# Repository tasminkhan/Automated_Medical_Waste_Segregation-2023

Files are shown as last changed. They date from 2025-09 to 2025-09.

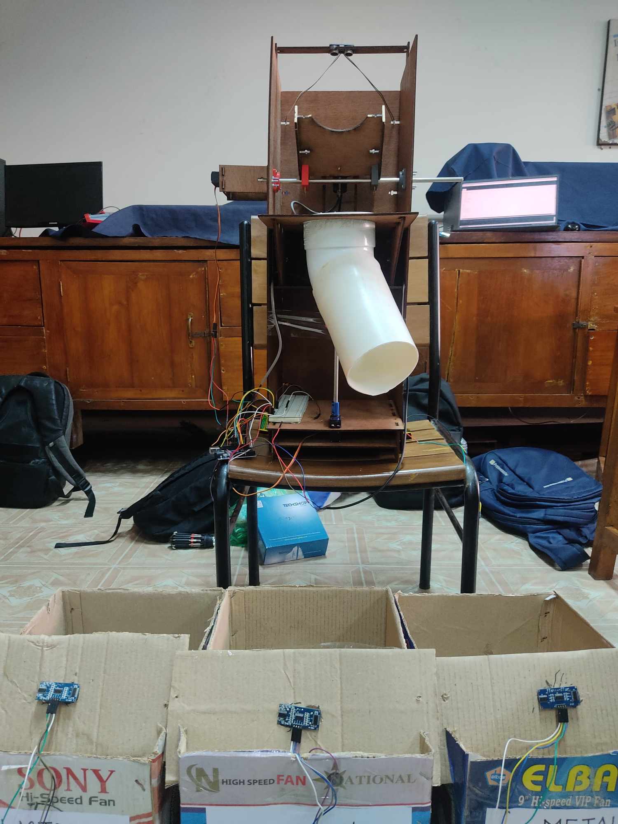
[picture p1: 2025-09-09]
media/laboratory setup.jpg

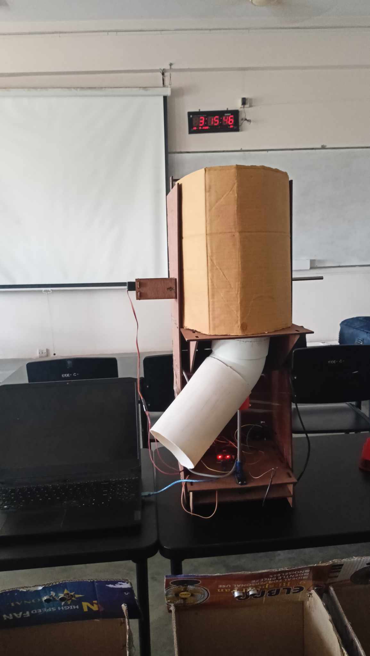
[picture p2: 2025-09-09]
media/model photo.jpg

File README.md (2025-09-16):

# Automated Smart Medical Waste Segregation System



An automated waste segregation system designed for medical facilities to efficiently sort waste into metallic, plastic, and organic categories using sensor technology and servo-controlled sorting mechanisms.

## Project Overview

This system addresses the critical need for proper medical waste management by automatically detecting and sorting different types of waste materials. The project focuses on healthcare applications where proper waste segregation is essential for safety and environmental compliance.

### Key Features

- **Multi-sensor Detection**: Uses capacitive, inductive, and ultrasonic sensors for waste identification
- **Automated V-Gate Sorting**: Servo motor-controlled mechanism for precise waste segregation
- **Smart Notifications**: Bluetooth-enabled system for waste bin level monitoring
- **Medical Focus**: Designed specifically for hospital and healthcare facility requirements
- **Sustainable Design**: Built with eco-friendly and cost-effective materials

## 🛠️ System Components

### Hardware
- **Microcontroller**: Arduino Uno
- **Sensors**: 
  - Capacitive proximity sensor (wet/organic waste detection)
  - Inductive proximity sensor (metal detection)  
  - 4x Ultrasonic sensors HC-SR04 (waste detection & bin level monitoring)
- **Actuators**: 2x TowerPro MG996R servo motors
- **Communication**: Bluetooth HC-05 module
- **Power**: 9V DC supply with step-down converter
- **Structure**: Laser-cut 4mm plywood frame, 3D printed components

### Software
- Arduino IDE for microcontroller programming
- SolidWorks for mechanical design
- Mobile app for notifications

## Performance Results

- **Detection Accuracy**: 90% (18/20 test samples)
- **Segregation Accuracy**: 80% (16/20 successful sorts)
- **Waste Categories**: Metal, Plastic, Organic/Biodegradable
- **Processing**: Real-time waste classification and sorting

## System Architecture

```
Waste Input → Ultrasonic Detection → Material Classification → V-Gate Sorting → Designated Bins
     ↓
Bin Level Monitoring → Bluetooth Alert → Mobile Notification
```

## How It Works

1. **Detection**: Ultrasonic sensor detects when waste is placed in the system
2. **Classification**: 
   - Metal waste: Both capacitive and inductive sensors detect
   - Organic/wet waste: Only capacitive sensor detects
   - Plastic waste: Neither sensor detects (default category)
3. **Sorting**: Servo motors control V-gate mechanism to direct waste to appropriate bin
4. **Monitoring**: Ultrasonic sensors in bins monitor fill levels
5. **Notification**: Bluetooth module sends alerts when bins reach 80% capacity

## Cost Analysis
**Total Project Cost**: 15,000 BDT (~$140 USD)

## Future Enhancements

- Integration of computer vision for improved detection
- Expansion to additional waste categories
- Central waste management dashboard

## References

This project builds upon established waste sorting principles and incorporates improvements for medical waste applications. 
- Instructables - [Automatic Waste Sorting Machine](https://www.instructables.com/Automatic-Waste-Sorting-Machine/)
- Ahmad, I., Mukhlisin, M., & Basri, H. (2016). Application of Capacitance Proximity Sensor for the Identification of Paper and Plastic from Recycling Materials.
- Wulandari, E. W. V. (2020). Waste segregator system design. IOP Conference Series: Materials Science and Engineering.
- Singh, N., Ogunseitan, O. A., & Tang, Y. (2022). Medical waste: Current challenges and future opportunities for sustainable management.

## 📄 License

This project is licensed under the MIT License - see the LICENSE file for details.

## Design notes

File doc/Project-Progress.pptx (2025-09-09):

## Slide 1

EEE 318: Control Systems I Laboratory

AUTOMATED
SMART WASTE
SEGREGATION

Project Progress

Group 06 | Presentation

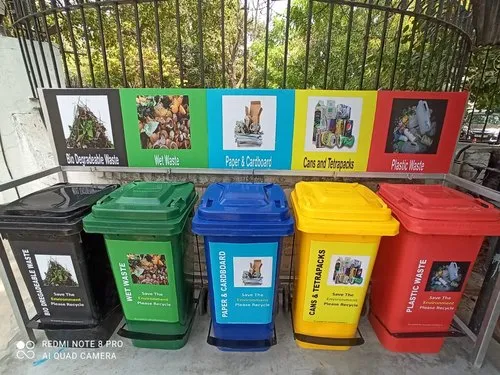
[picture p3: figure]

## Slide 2

EXPECTED STRUCTURE

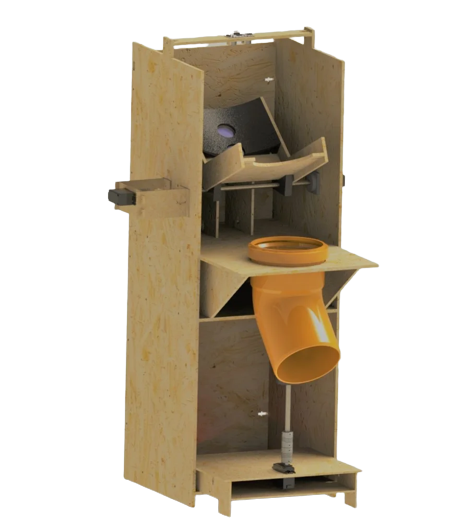
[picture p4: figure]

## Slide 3

PHYSICAL STRUCTURE

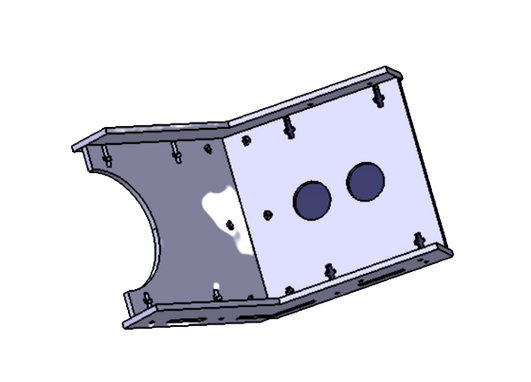
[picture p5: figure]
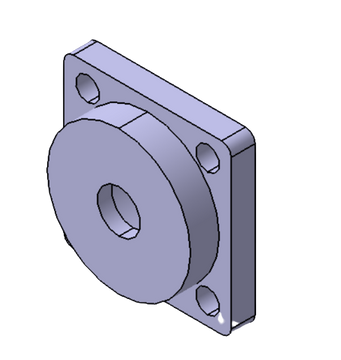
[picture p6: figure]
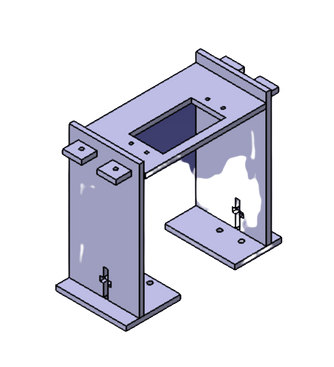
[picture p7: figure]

3D PRINTED PARTS

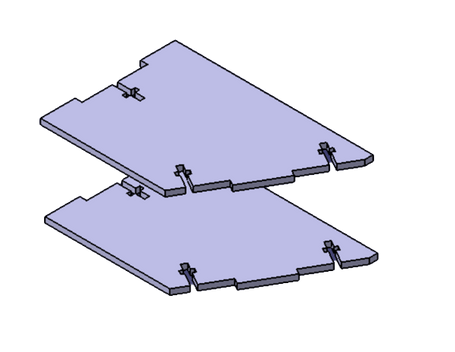
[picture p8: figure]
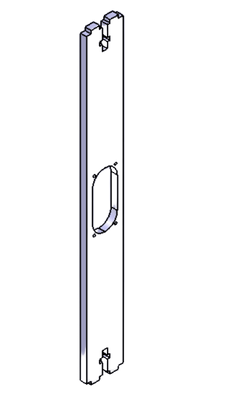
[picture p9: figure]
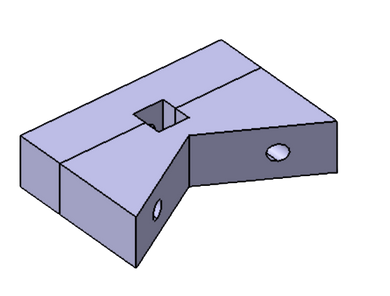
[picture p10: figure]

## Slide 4

PHYSICAL STRUCTURE

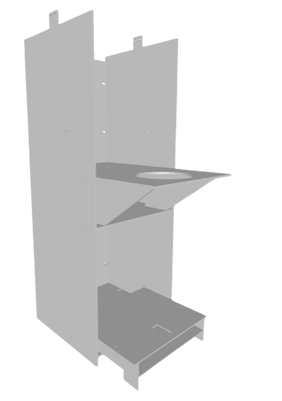
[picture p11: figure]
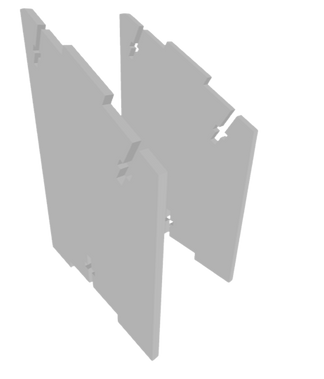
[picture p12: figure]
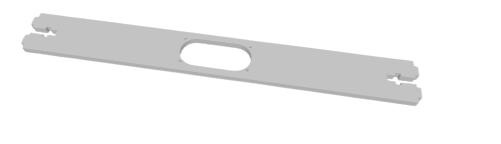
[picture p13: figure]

LASER CUT PARTS

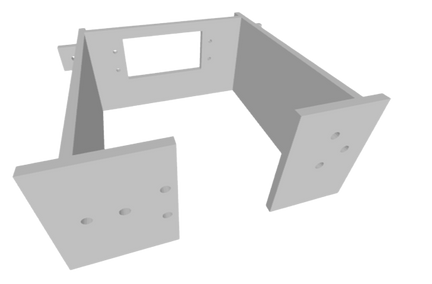
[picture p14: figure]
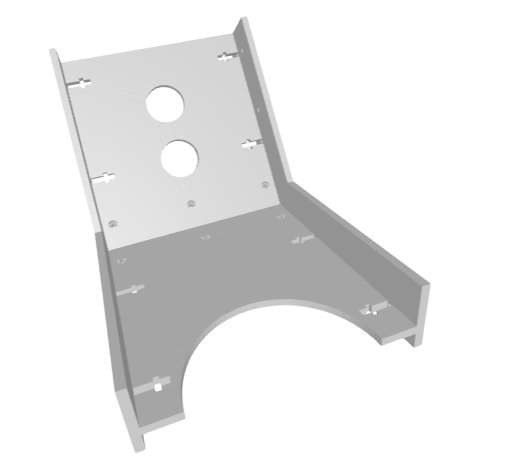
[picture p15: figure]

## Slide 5

MOTOR CALCULATION

Wood Density, d= 0.600 gm/cc
Volume (CAD design), V= 206.4 cc
Total weight= d*V/1000= 0.12348 kg
W1=W2=(0.12348*9.8)/2= 0.61 N
Let us take a maximum waste mass, MWM=0.72 Kg
Torque F*L=MWM*9.8*150 +0.61*75-0.61*cos(60)*75
F*L=104.95 N-mm=1.72875 kg-cm
Yield Strength, T=250 MPa=250 N/sq. mm
T= (F/A)/(d/L)=(F*l)/(A*l)=(F*l)/V=(104.95)/V
V= (1/16) * pi * d^3
d= 4mm

W1

75 mm

W2

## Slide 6

MOTOR CALCULATION

Specifications of MG 996R

MWM= 0.72 Kg
Using simple approximations, torque T= 0.72*7.5*sin(120)
T= 4.8 kg-cm

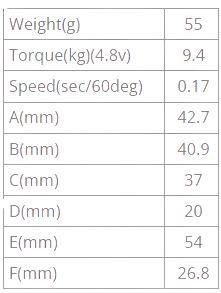
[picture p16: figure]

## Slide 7

DETECTION

IR sensor

Capacitive Soil Moisture Sensor

ORGANIC

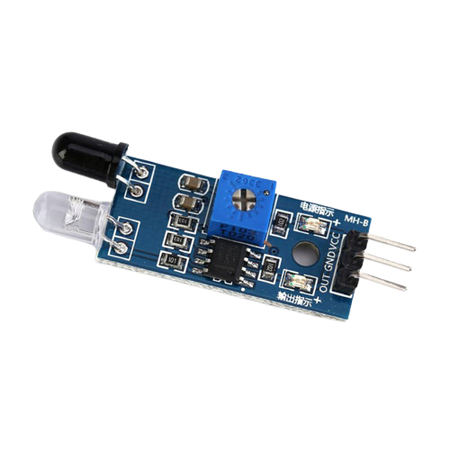
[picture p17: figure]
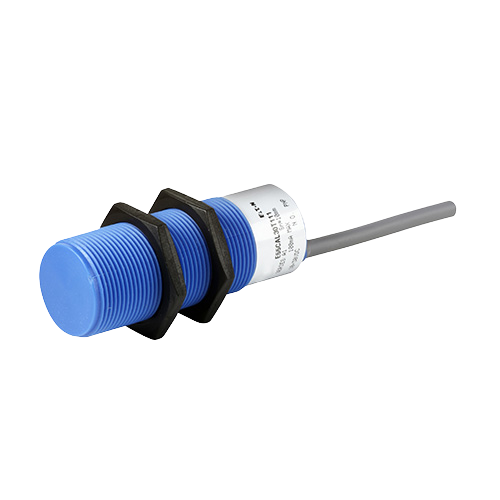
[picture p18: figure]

Inductive Proximity Sensor

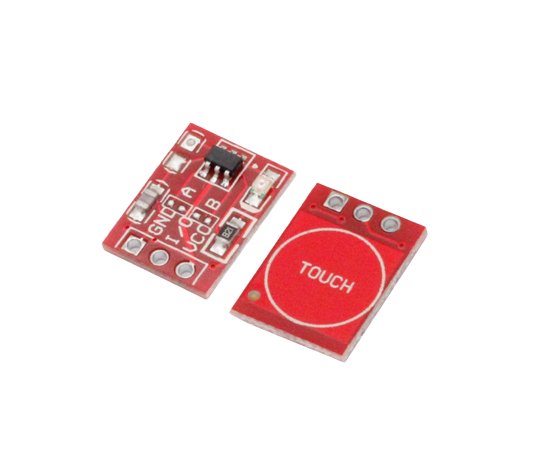
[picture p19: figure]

Capacitive touch Sensor

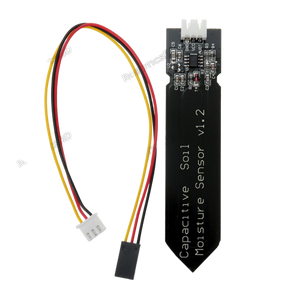
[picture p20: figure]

METAL

PLASTIC

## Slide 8

LOGIC DEVELOPMENT

Case | Inductive | Capacitive | Soil Sensor
Metal | No | Yes | No
Plastic | Yes | Yes/no | No
Organic | No | No | Yes

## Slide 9

LOGIC DEVELOPMENT

Case | Inductive | Capacitive | IR sensor
Metal | No | Yes | X
Plastic | Yes | X | X
Organic | No | No | Yes

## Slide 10

DIFFICULTIES

  - Absolute Dryness of internal structure: Capacitive Soil Moisture sensor detects even the slightest moisture. Possible solution: Paint coating.

  - IR sensor: Alternative process is to first cross out metal and plastic and use IR sensor to detect waste and label it organic.

  - Pipe Dynamics: Try and test pipe dynamics to see if motion is as predicted.

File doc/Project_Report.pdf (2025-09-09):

# Automated Smart Medical Waste

# Segregation

Abstract— Improper waste disposal poses significant challenges to
human | health | and | the | environment | worldwide, | with | the
overproduction of toxic waste and outdated waste management practices. Our project introduces an innovative solution – an Automated Smart Medical Waste Segregation system, designed to revolutionize waste treatment processes while aligning with several Sustainable Development Goals (SDGs), including 'Good Health & Well-Being,' 'Industry, Innovation & Infrastructure,' 'Sustainable Cities & Communities,' and 'Climate Action’. Our approach features capacitive, inductive, and ultrasonic sensors to identify three critical categories of waste materials: wet, plastic, and metallic waste. Through a V-gate mechanism, the system facilitated by TowerPro MG996R servo motors, swiftly and accurately segregates incoming waste, directing each material through a pipe to its designated bin. The system’s microcontroller, an Arduino Uno, powers the sensors and manages the segregation process. As part of our sustainable vision, we are actively exploring the replacement of the Arduino Uno with rechargeable batteries or renewable energy sources, such as solar power. The choice of plywood for the structure of our prototype shows our commitment to fostering eco-friendly practices in waste management and minimizing environmental impact.

Keywords— capacitive proximity sensor, inductive proximity sensor, ultrasonic sensor, servo motor, V-gate, GSM module, Bluetooth module

I. INTRODUCTION

Not all waste is disposed of in the same way, the process of disposal varies according to the type of waste. Some waste is biodegradable, some is recyclable and reusable, and some is to be handled with ultimate care. So, segregating waste is a must, especially in the medical sector. An automated smart machine can be a solution to this problem.

Our project’s goal is to sort at least three different types of waste: plastic, metal, and wet and biodegradable waste. These three types of waste are mostly produced in hospitals. The medical sector generates a diverse range of waste materials, including metal, plastic, and biodegradable waste. Metal waste in healthcare primarily consists of discarded medical instruments and equipment, such as surgical tools and implant materials. Proper disposal and recycling of metal waste are essential to reduce environmental impact and resource depletion. Plastic waste is another significant concern in the medical field, encompassing single-use items like syringes, IV bags, and packaging materials. The persistence of plastics in the environment poses environmental threats, making proper disposal and recycling crucial. Efforts to reduce plastic usage through alternative materials and recycling initiatives are gaining traction. In contrast, biodegradable waste, such as organic matter from surgical procedures or expired medications, has the potential to break down naturally. However, even biodegradable waste management must be carefully controlled to prevent contamination and ensure safe disposal methods.

II. LITERATURE REVIEW

Medical waste management is a critical aspect of healthcare operations. Effective waste segregation is vital to ensure the safety of healthcare workers, patients, and the environment. In recent years, automated waste segregation systems employing inductive and capacitive proximity sensors have gained attention as a means to enhance the accuracy and efficiency of this critical process. For sensing capability systems, proximity sensors are wildly used in industries using food beverages, chemical processing, functionality etc. As fast as 5,000 Hz, proximity sensors can operate with accuracy and repeatability, meeting the demands of a variety of high-speed industrial applications. The proximity sensor will give precision to preserve efficiency and the product's efficacy because the calculation may be made to within 0.001 in. (Irfana et al[1], 2016).

A waste segregator system that was designed where waste inserted with sizes greater than 5 cm into different categories of metal and non-metallic (wet and dry) waste. Only when the inductive proximity sensor is 0-8 mm and the capacitive proximity sensor is 0-12 mm away from the object (trash) can the system of this tool function. With testing utilizing 2 waste objects tested 5 times for each location of waste sorting, the percentage of success attained for sorting non-metallic waste (dry) is 100%, non-metallic waste (wet) is 80%, and metal waste is 100%. (Enina Wika et al[2], 2019)

According to statistical correlations with the human development index (HDI), life expectancy (LE), healthcare expenditure (HE) per capita of gross domestic product (GDP), and environmental performance index (EPI), only 41% of employees had received in-service training in the proper handling of medical waste, and only an average of 38.9% of medical waste was segregated. (YuanYuan et al[3], 2021)

Tasnimun Razin
Student ID: 1906044
Department of EEE, BUET
Dhaka, Bangladesh
Email: 1906044@eee.buet.ac.bd
K. M. Azmain Rafin
Student ID: 1906045
Department of EEE, BUET
Dhaka, Bangladesh
Email: 1906045@eee.buet.ac.bd

Md. Fahadul Islam
Student ID: 1906054
Department of EEE, BUET
Dhaka, Bangladesh
Email: 1906054@eee.buet.ac.bd

Tasmin Khan
Student ID: 1906055
Department of EEE, BUET
Dhaka, Bangladesh
Email: 1906055@eee.buet.ac.bd

Ismam Nur Swapnil
Student ID: 1906064
Department of EEE, BUET
Dhaka, Bangladesh
Email: 1906064@eee.buet.ac.bd

A.K.M. Anindya Alam
Student ID: 1906065
Department of EEE, BUET
Dhaka, Bangladesh
Email: 1906065@eee.buet.ac.bd

I. METHODOLOGY

The flow chart of the working procedure of the project is given below:

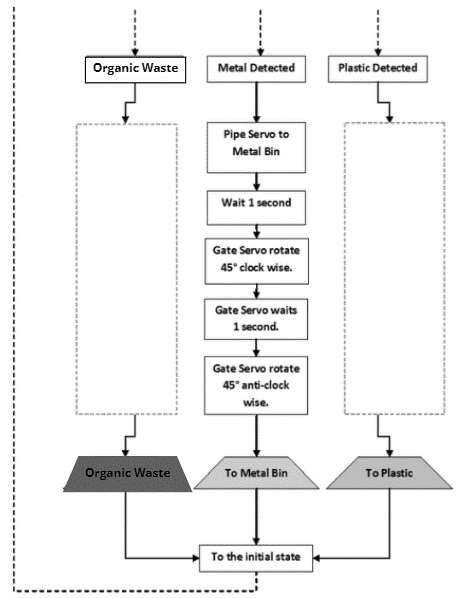
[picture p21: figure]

A. Necessary Equipment and Materials

For this project, we needed some mechanical equipment, which we got from 3D print and laser-cut. Shaft cover, pipe support, V-gate Shaft-Bearing support, and V-gate support were 3D printed. On the other hand, the frame, V-gate, Ultrasonic sensor support, Capacitive and Inductive sensor support, and V-gate motor support were laser-cut. The materials we used for the equipment are mostly biodegradable or reusable. We utilized 4mm plywood, 1pc 125mm Upvc elbow, 1pc 125mm UPVC pipe, 1pc 8mm Ss Shaft for motor, 2pcs Servo Motor Coupler, 2pcs radial bearing, and necessary screws and nuts.
Apart from the mechanical equipment, we also needed some electronic components. We used one Arduino Uno, one Prototyping board, Soldering material, and equipment, one inductive sensor, one capacitive sensor, four ultrasonic sensors, two servo motors, one step down converter, one DC power supply and necessary wires and jumpers.
For the software part, we used SolidWorks, Rhinoceros and Arduino.

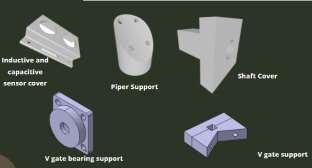
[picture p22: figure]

Figure: 3D printed Parts

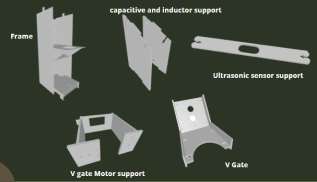
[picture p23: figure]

Figure: Laser Cut Parts

B. Gate Shaft Calculation:
Here, the wood density, d= 0.600gm/cc, volume (According to the CAD design), V= 206.4cc.
So, the total weight= d*V/1000 = 0.12348kg
The two parts of the V-gate have the same weight =
0.12348∗9.8
2

= 0.61N

Let us take a maximum waste mass, MWM = 0.72 kg. Torque = F ∗ L= MWM*9.8*150 + 0.61*75 – 0.61*cos(60)*75 = 104.95 N-mm = 1.72875 kg-cm Yield Strength, T = 250 MPa = 250 N/mm²

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
= 104.95/V

V= (

1
16) ∗ d
3
∗π

d= 4mm

C. Motor Calculation:
Here, MG 996R has these specifications:
Weight= 55g, Torque(kg)(4.8v)= 9.4, speed= 0.17sec
60deg

,

A= 42.7mm, B= 40.9mm, C= 37mm, D= 20mm, E= 54mm, F= 26.8mm.
MWM = 0.72 kg.
Using simple approximations, torque, T= 0.72*7.5* sin(120)
T= 4.8 kg-cm
D. Detection and Logic Development:

We have used three types of sensors for detecting different kinds of waste: one ultrasonic sensor, one capacitive sensor and one inductive sensor. The ultrasonic sensor detects whether any waste is put or not.

For metal waste, both capacitive and inductive sensors detect the waste, and show the result later by moving the servo motor. For the wet and organic waste, the capacitive sensor works, but the inductive sensor does not. When none of these two sensors can detect the waste, then it is detected as a plastic waste.

E. Feedback From Waste Bins

When the Waste box is filled, an alert system is activated, and the cleaner assigned to discharge the box receives an SMS. For this, a Bluetooth HCO5 module is needed, along with one Arduino UNO, three ultrasonic sensors, one breadboard, some jumper wires, and a battery.
The Bluetooth Module is powered by Arduino Uno. In the Arduino code, we set the level (80%) that the box is filled with waste. Here, basically, we set the distance between the ultrasonic sensor and the waste level. Moreover, the cleaner also requires having an app installed and opened in his mobile to receive the SMS.

II. DESIGN

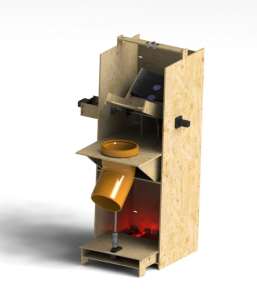
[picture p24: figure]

Figure: Primary Structure

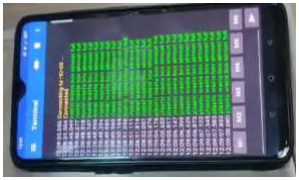
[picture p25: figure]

Figure: Output from Bluetooth Module (Notification system)

III. RESULTS
We used around 20 individual wastes to test our system. Out of which 18 were successfully detected but 16 were successfully dumped into designated waste basket. We faced some problems with disposal of waste after the v-gate due to friction which lowered our accuracy for segregation,

Detection accuracy: 90 percent
Segregation accuracy: 80 percent

IV. NOVELTY

A. Very Low installation Cost

Instead of importing, sourcing local materials and using available components, we were able to reduce the cost. The overall cost is around 15,000 BDT.

B. Use of Biodegradable or Recyclable Materials

We have used plywood, metal shaft, PVC pipe etc. in this project. Among them, PVC pipes can be replaced with PLA, which is a biodegradable plastic. Thus, our project will be more environmental-friendly.

C. Push Notification System

As we have implemented a push notification system in our project, the cleaner does not have to check the waste boxes every now and then. When the box is filled with waste, he/ she automatically receives a message on the phone app. So better time management is ensured.

Multiple waste boxes can be handled simultaneously. Whenever any box is filled, the cleaner receives the message of that box.

V. FUTURE SCOPES AND
SCALABILITY
A. Improvement in waste sortation with object detection algorithm. We would want to use a limited number of sensors to improve detection.
B. Using Choetsu for waterproof coating which is completely biodegradable. It is a special water
proof | coating | that | is | biodegradable | and
environment friendly.
C. We’ve used 9V non-rechargeable batteries. We can easily replace it with LiPo batteries and use different rechargeable batteries to increase energy efficiency.
D. Increasing the categories of waste to segregate hence improve waste handling by using more precise and a wide range of sensors.
E. Bulk produced from molds instead of 3D printed and PVC parts would reduce a lot of material cost as well as making the design more environment friendly.
F. The ultimate goal is it to have this system be used as central waste collection and segregation system so that we can segregate and dispose of the wastes of an entire facility and increasing the scope of application.
G. The notification feature needs to implemented centrally and using GSM800L sim module instead of Bluetooth and wi-fi connection to allow everyone to have access to information about the type and amount of waste collected so that costs and other measures can be taken accordingly backed up by statistical data.

VI. QUOTES FROM EXPERTS

“Biomedical Waste Disposal is an essential commitment to providing our patients with a safe and hygienic experience. And that will only be effective by filtering out hazardous elements and taking proper safety measure to handle so.”
- Dr. Manifa Afrin
Associate Professor, ChildCare
Universal Medical College and Hospital

“Incinerating different materials may produce different toxic, especially metal. Again, reusable plastics also need to be segregated for sterilization in hot air oven, sterilizing it along with metals may cause shrinkage or tempering of the equipment.”
- Dr. Ching Key Prue
Medical Intern, Armed Forces Medical College and Hospital

“Such a system can be useful for implementing in places with high crowd where there is no effective segregation system, yet the amount of waste disposal is huge.”
- Dr. Radwana Noor
Medical Officer, Shahed Suhrawardy Medical College and Hospital
VII. | COST ANALYSIS

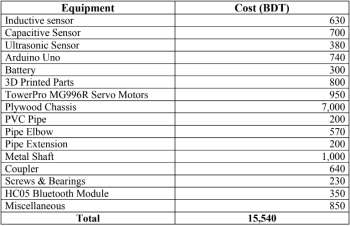
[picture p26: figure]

VIII. | CONCLUSION

The main goal of the project was to segregate waste in an environmentally friendly way in order to save time and reduce health hazards. We used ultrasonic sensors to identify the existence of the waste, then detected it with capacitive and inductive sensors. Next, we used servo motors to throw the waste in their respective bins.

We conducted several tests to calculate and improve the success rate of our project. Our system was successful in identifying the object in 90 percent cases, and in 80 percent cases, it could segregate rightly. This accuracy can be increased by taking the necessary steps as mentioned before. Thus, the project can be implemented in larger scale, which will be a revolution in the sector of waste segregation in our country, especially in medical sector.

IX. ACKNOWLEDGEMENTS

It will not have been possible for us to develop this project without the guidance of Professor Dr. Celia Shahnaz. Her motivation and rigorous input helped us improve our ideas significantly. We are grateful to her. We would like to thank Md. Jawad Ul Islam Sir for constantly providing us with resources, inputs and answering our queries throughout the process. They helped us a lot, provided us with advice, and continuously monitored the progress of our project.

X. REFERENCES
[1] Ahmad, Irfana & Mukhlisin, Muhammad & Basri, Hassan. (2016). Application of Capacitance Proximity Sensor for the Identification of Paper and Plastic from Recycling Materials. Research Journal of Applied Sciences,
Engineering | and | Technology. | 12. | 1221-1228.
10.19026/rjaset.12.2880.
[2] Enina Wika Vetricha Wulandari 2020 IOP Conf. Ser.:
Mater. | Sci. | Eng. | 725 | 012054,DOI | 10.1088/1757-
899X/725/1/012054
[3] Narendra Singh, Oladele A. Ogunseitan & Yuanyuan Tang (2022) Medical waste: Current challenges and future opportunities for sustainable management, Critical Reviews in Environmental Science and Technology, 52:11, 2000-
2022, | DOI: | 10.1080/10643389.2021.1885325
[5] “Automatic Waste Sorting Machine.” Instructables, www.instructables.com/Automatic-Waste-Sorting-Machine/?fbclid=IwAR1JK79m6RqA9mhfPaLddLS2BE-MOk2zLcXIRt2IOr0Z26NrE35pyDxQ6Q

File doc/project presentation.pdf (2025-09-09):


# Automated Smart Medical Waste Segregation

Presented by
Group 06
ID: 1906044
1906045
1906054
1906055
1906064
1906065

Presented to

Dr Celia Shahnaz
Professor, BUET EEE

Jawad Ul Islam
PT, BUET EEE

# Working procedure

We use a combination of inductive, capacitive and ultrasonic sensor to detect the presence as well as the nature of waste, Finally we used two servo motors to segregate the waste.

We have also set up a system to send notification when the waste boxes will be full.

Type of waste | Inductive sensor | Capacitive sensor | Ultrasonic sensor
Metal | yes | yes | yes
Plastic | no | no | yes
Wet waste | no | yes | yes


## Testing

We used around 20 individual wastes to test our system. Out of which 18 were successfully detected but 16 were successfully dumped into designated waste basket. We faced some problems with disposal of waste after the v-gate due to friction which lowered our accuracy for segregation,

Detection accuracy: 90 percent
Segregation accuracy: 80 percent

## Novelty

Very low installation cost (around 12,000)
Instead of importing, sourcing local materials and using available components, we were able to reduce the cost.
Use of biodegradable or recyclable materials (Plywood, PLA, metal shaft etc)
PLA is a biodegradable plastic. We have currently used PVC pipe in our project which can be later made from PLA using moulds for bulk produce once commercialized.
Push Notification system
We have also implemented a system to send information to concerned authority via phone when the waste boxes need replacement.

## Future scopes and scalability

- Improvement in waste sortation with object detection algorithm
- Using Choetsu for waterproof coating which is completely biodegradable
- Using Rechargeable Battery for power supply to reduce waste
- Increasing the categories of waste to segregate hence improve waste handling
- Using bulk produce from moulds instead of 3d printed and pvc parts
- Expanding it to be used as central waste collection and segregation system

# Quotes from Experts

“Biomedical Waste Disposal is an essential commitment to providing our patients with a safe and hygienic healthcare experience. And that will only be effective by filtering out hazardous elements and taking proper safety measure to handle so“

“Incinerating different materials may produce different toxins, specially for metal. Again, reusable plastics also need to be segregated for sterilization in hot air oven, Sterilizing it along with metals may cause shrinkage or tempering of the equipment”

“Such a system can be useful for implementing in places with high crowd where there is no effective segregation system yet the amount of waste disposal is huge”

Dr. Manifa Afrin
Associate professor cc
Universal Medical
College and Hospital

Dr. Ching Key Prue
Medical Intern
Armed Forces Medical
College and Hospital

Dr. Radwana Noor
Medical Officer
Shaheed Suhrawardy
Medical College and Hospital

# Cost Analysis

ITEM | COST | ITEM | COST
Inductive sensor | 630 | Arduino | 600
Capacitive sensor | 700 | Battery | 300
Ultrasonic sensor | 350 | 3d printed parts | 300
Servo motor | 300 | Wooden chassis | 7000
Metal Shaft | 1000 | Pvc pipe | 200
Bluetooth module | 350 | Miscellaneous | 1000
Total cost | | 12830

# Target SDG goals


# Thanks!

## Any Questions?

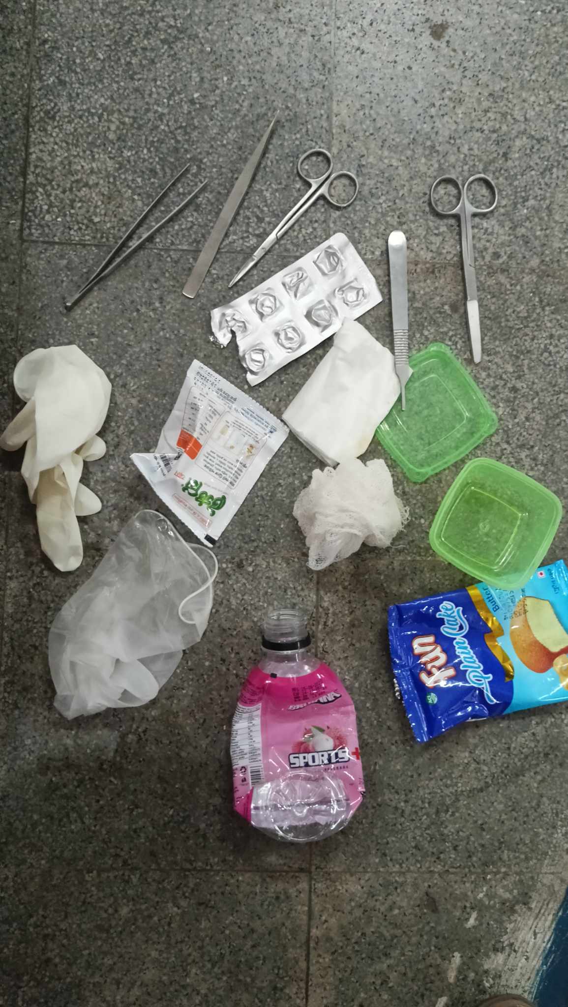
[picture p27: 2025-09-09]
media/types of wastage'.jpg

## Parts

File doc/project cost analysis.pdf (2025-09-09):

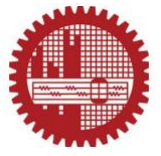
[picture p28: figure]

Bangladesh University of Engineering and Technology

Department of Electrical and Electronic Engineering

Course Number : EEE 318

Course Title : Control Systems I Laboratory

Title of the Project

AUTOMATED SMART MEDICAL WASTE SEGREGATION

Submitted by: | Presented to:
1906044: Tasnimun Razin | Dr. Celia Shahnaz
1906045: K.M. Azmain Rafin | Professor
1906054: Md. Fahadul Islam | Department of EEE, BUET

1906055: Tasmin Khan

1906064: Ismam Nur Swapnil | Md. Jawad Ul Islam
1906065: A.K.M. Anindya Alam | Adjunct Lecturer
| Department of EEE, BUET
Group: 06

Section: A2

Level: 3, Term: 2

Department: EEE

ABSTRACT

Improper waste disposal poses significant challenges to human health and the environment worldwide, with the overproduction of toxic waste and outdated waste management practices. Our project introduces an innovative solution - an Automated Smart Medical Waste Segregation system, designed to revolutionize waste treatment processes while aligning with several Sustainable Development Goals (SDGs), including 'Good Health & Well-Being,' 'Industry, Innovation & Infrastructure,' 'Sustainable Cities & Communities,' and 'Climate Action’.

Our approach features capacitive, inductive, and ultrasonic sensors to identify three critical categories of waste materials: wet, plastic, and metallic waste. Through a V-gate mechanism, the system facilitated by TowerPro MG996R servo motors, swiftly and accurately segregates incoming waste, directing each material through a pipe to its designated bin. The system’s microcontroller, an Arduino Uno, powers the sensors and manages the segregation process. As part of our sustainable vision, we are actively exploring the replacement of the Arduino Uno with rechargeable batteries or renewable energy sources, such as solar power. The choice of plywood for the structure of our prototype shows our commitment to fostering eco-friendly practices in waste management and minimizing environmental impact.

EQUIPMENT LIST WITH COST ANALYSIS

Equipment | Cost (BDT)
Inductive sensor | 630
Capacitive Sensor | 700
Ultrasonic Sensor | 380
Arduino Uno | 740
Battery | 300
3D Printed Parts | 800
TowerPro MG996R Servo Motors | 950
Plywood Chassis | 7,000
PVC Pipe | 200
Pipe Elbow | 570
Pipe Extension | 200
Metal Shaft | 1,000
Coupler | 640
Screws & Bearings | 230
HC05 Bluetooth Module | 350
Miscellaneous | 850
Total | 15,540

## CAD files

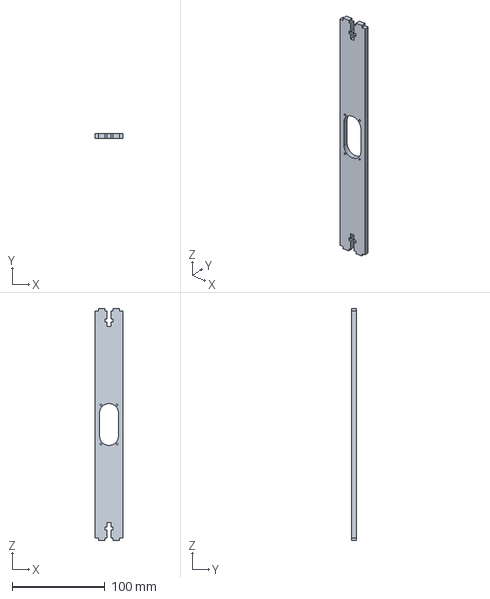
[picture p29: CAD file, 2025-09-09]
hardware CAD files/3D print parts/Ultrasonic sensor support.stp
30.0 x 5.00 x 250.0 mm

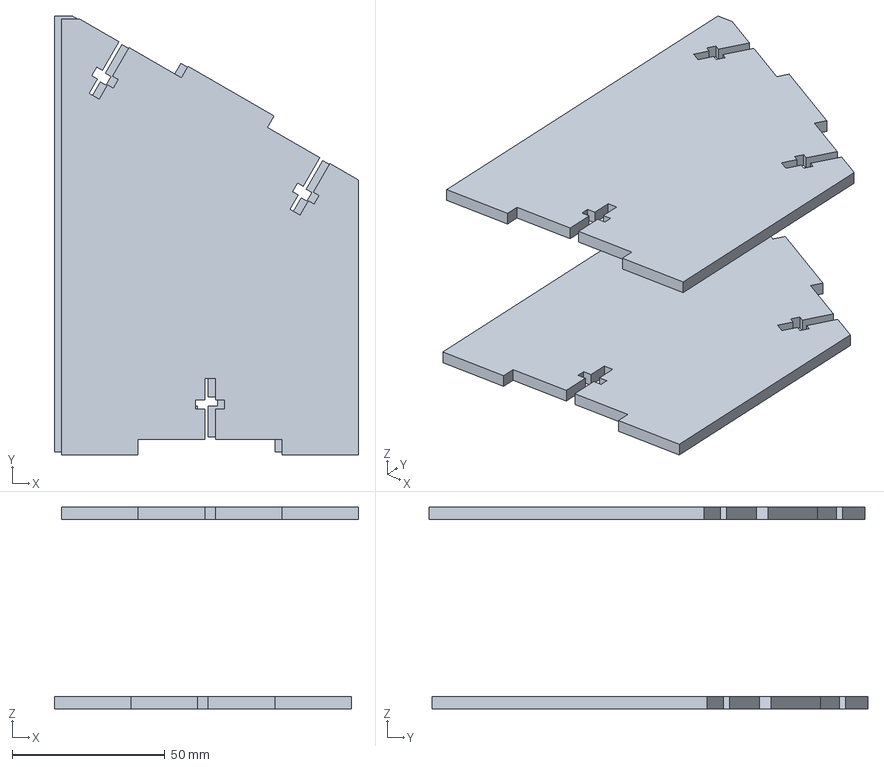
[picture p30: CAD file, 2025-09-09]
hardware CAD files/3D print parts/Capacitive and inductive sensor support.stp
99.6 x 143.7 x 66.0 mm

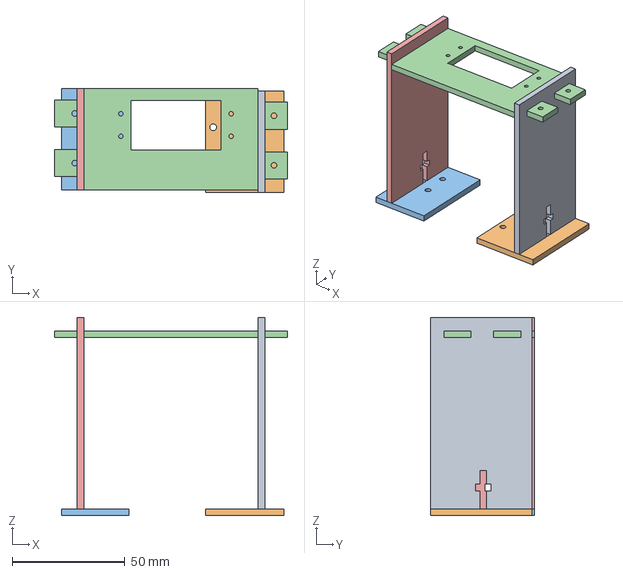
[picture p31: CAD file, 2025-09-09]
hardware CAD files/3D print parts/V gate motor support.stp
103.5 x 46.0 x 88.0 mm

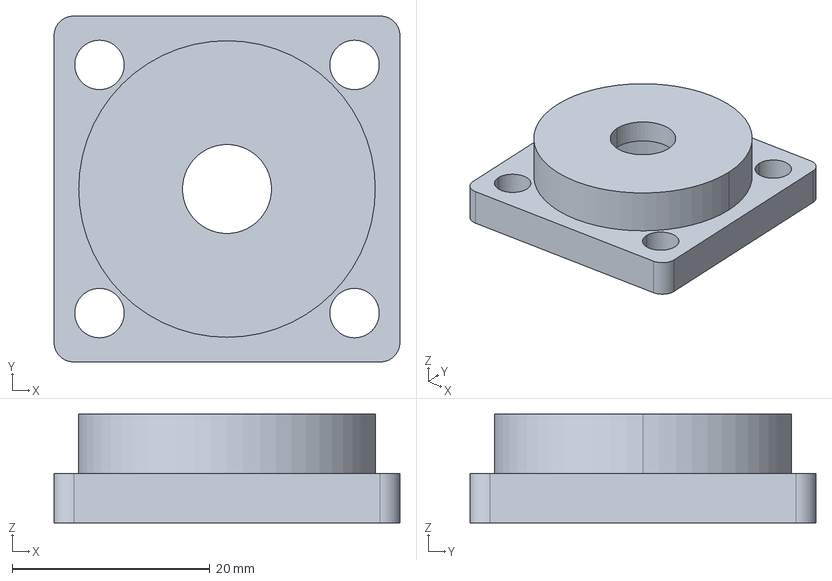
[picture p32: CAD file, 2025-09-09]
hardware CAD files/3D print parts/V gate shaft bearing support.stp
35.0 x 35.0 x 11.0 mm
Vgate final

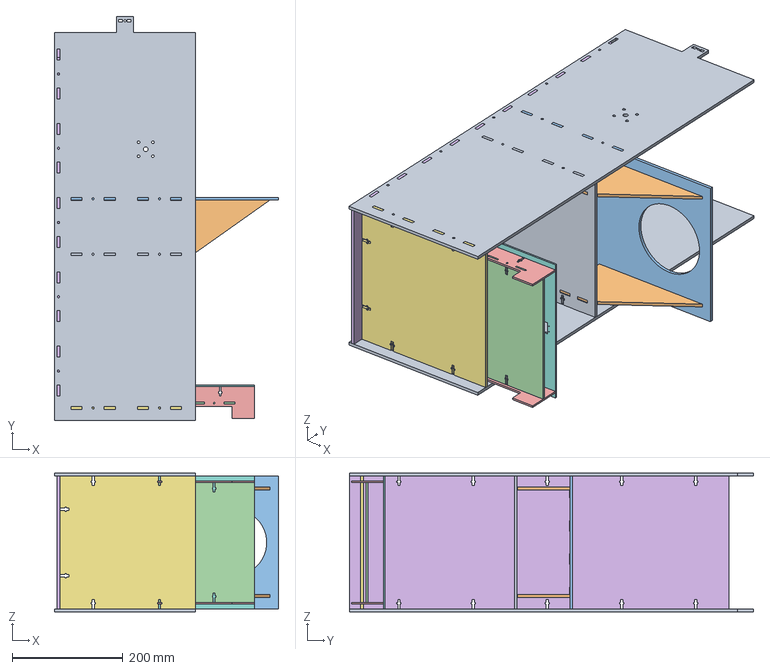
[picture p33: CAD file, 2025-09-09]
hardware CAD files/3D print parts/Frame.stp
405.0 x 729.2 x 250.0 mm

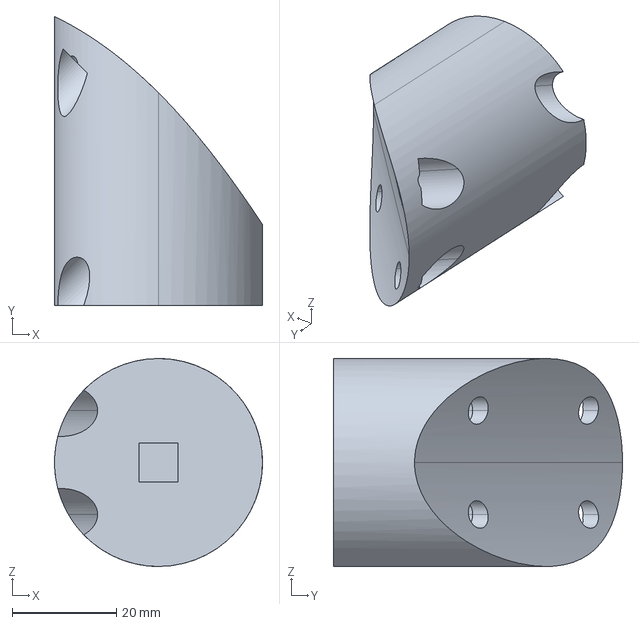
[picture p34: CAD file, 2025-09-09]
hardware CAD files/3D print parts/pipe support.stp
40.0 x 55.6 x 40.0 mm

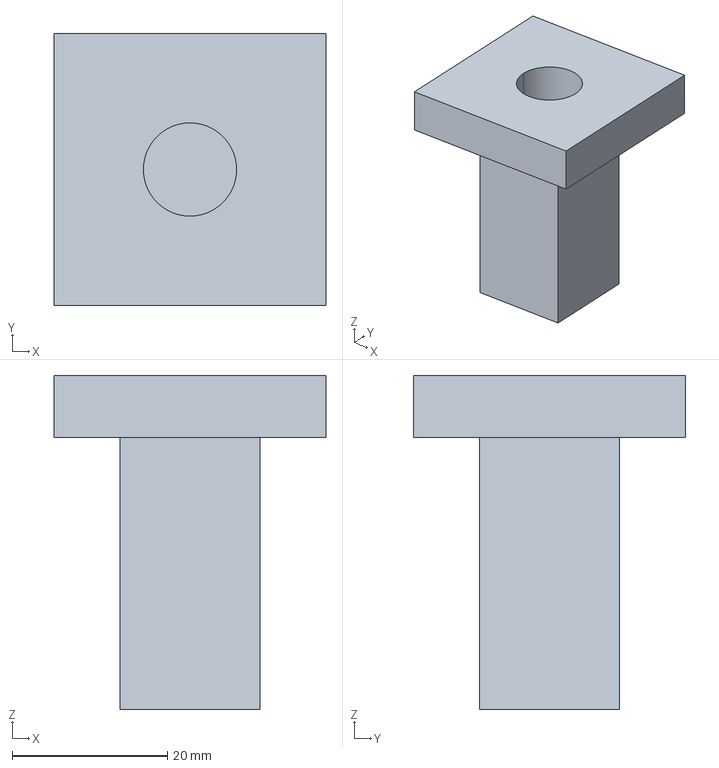
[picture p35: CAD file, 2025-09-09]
hardware CAD files/3D print parts/shaft cover.stp
35.0 x 35.0 x 43.0 mm

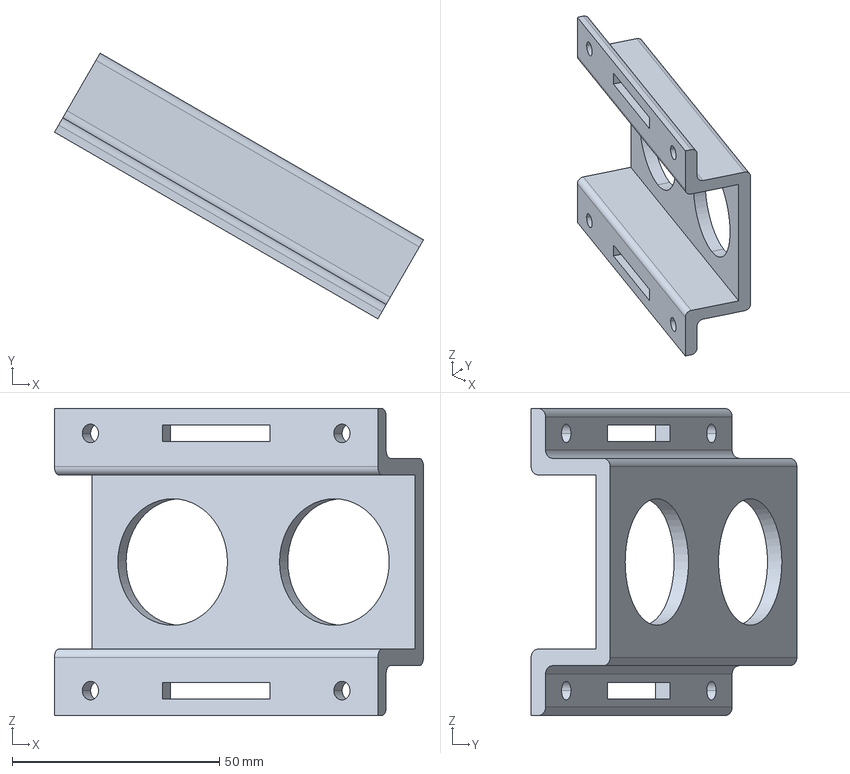
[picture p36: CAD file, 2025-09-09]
hardware CAD files/3D print parts/Inductive and capacitive sensor cover support.stp
88.9 x 64.1 x 74.0 mm

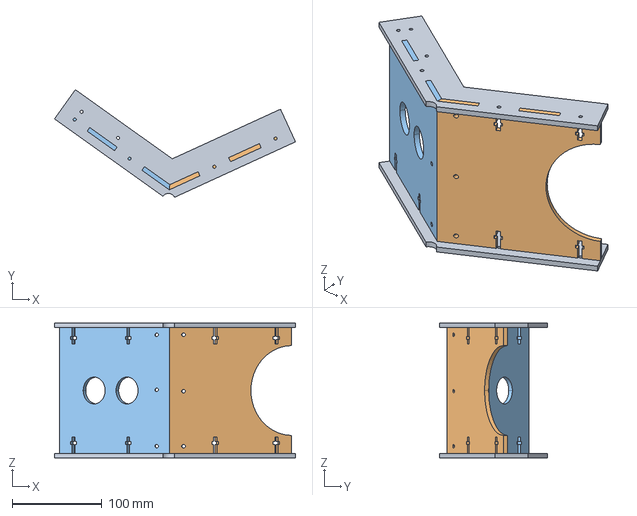
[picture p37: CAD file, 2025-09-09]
hardware CAD files/3D print parts/V gate.stp
268.4 x 119.9 x 150.0 mm

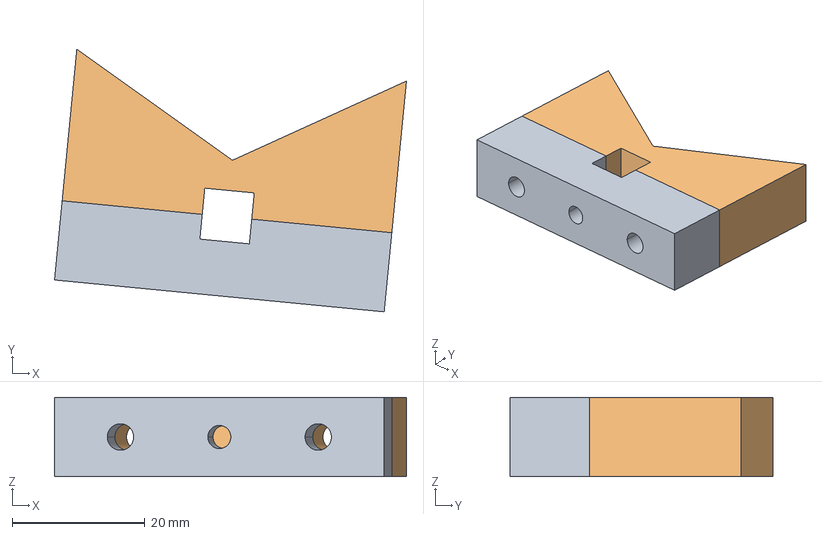
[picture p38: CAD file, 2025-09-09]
hardware CAD files/3D print parts/V gate support.stp
53.1 x 39.6 x 12.0 mm

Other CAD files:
hardware CAD files/Laser cut parts/frame dimensions.DWG

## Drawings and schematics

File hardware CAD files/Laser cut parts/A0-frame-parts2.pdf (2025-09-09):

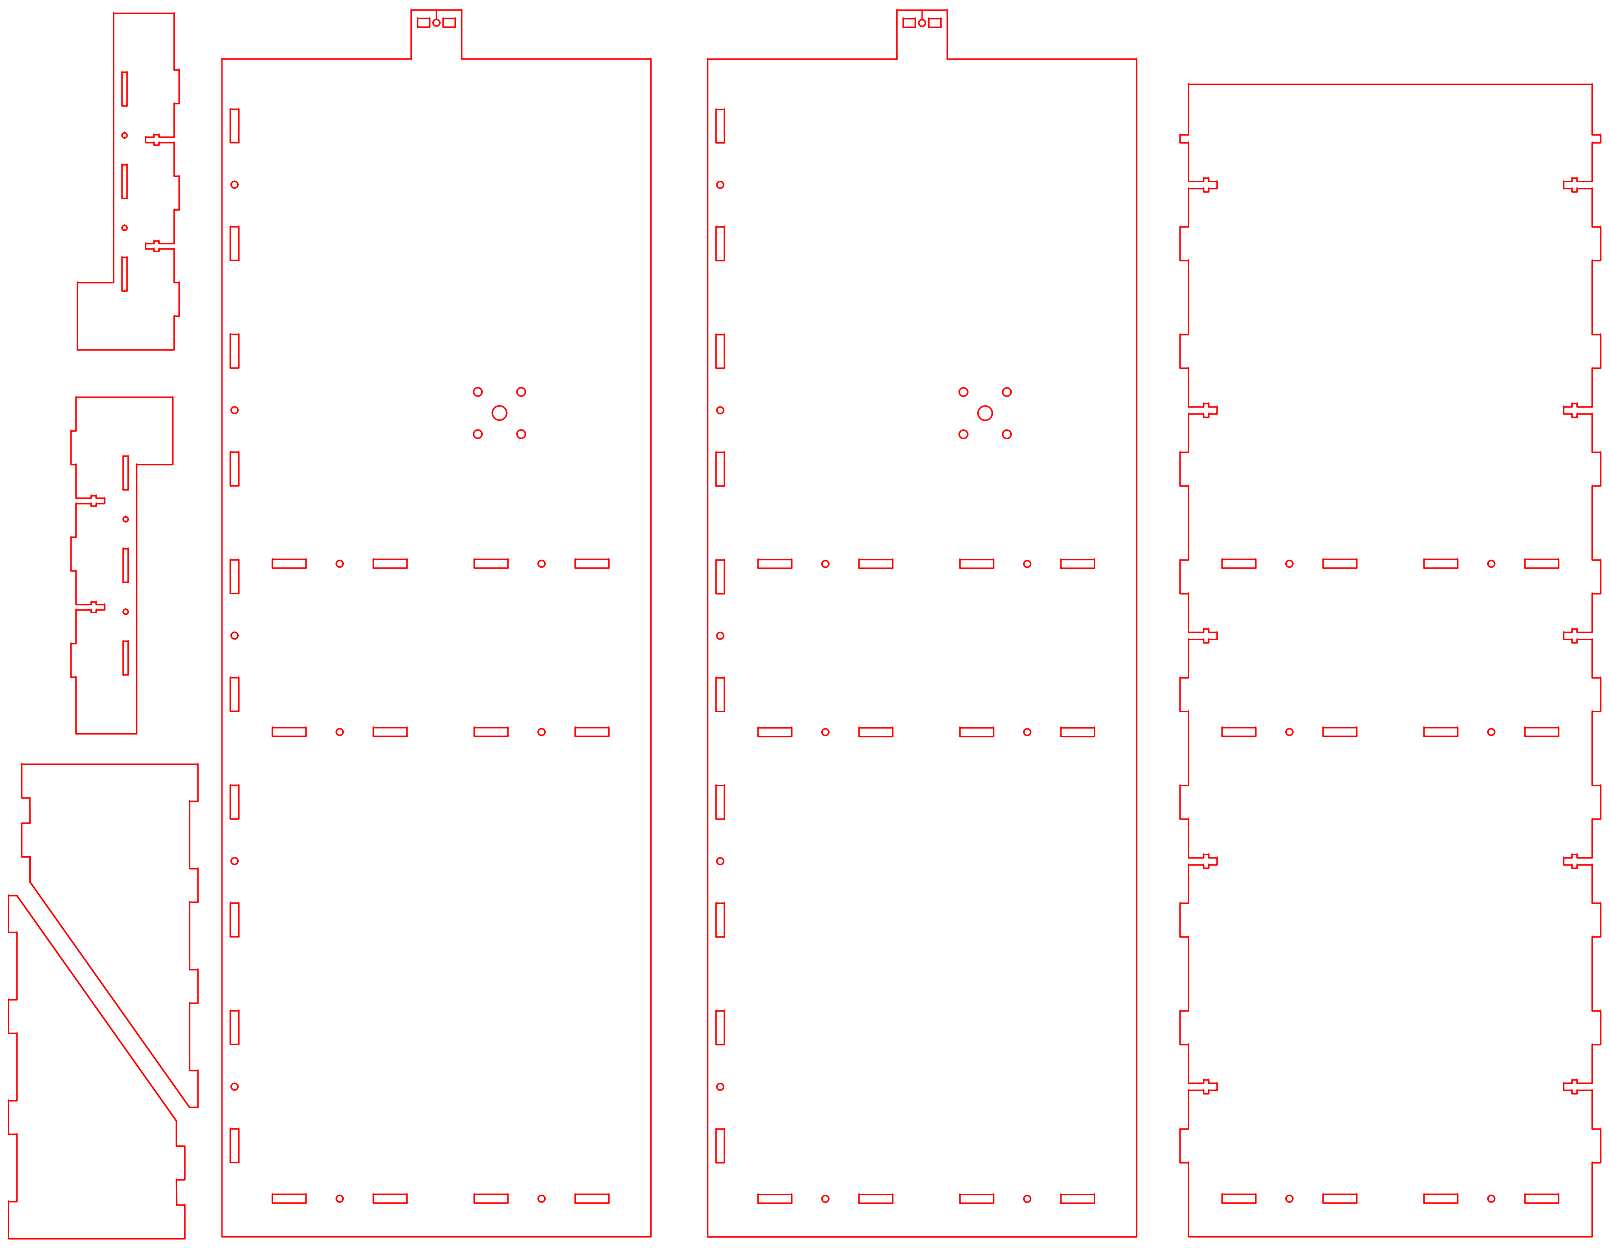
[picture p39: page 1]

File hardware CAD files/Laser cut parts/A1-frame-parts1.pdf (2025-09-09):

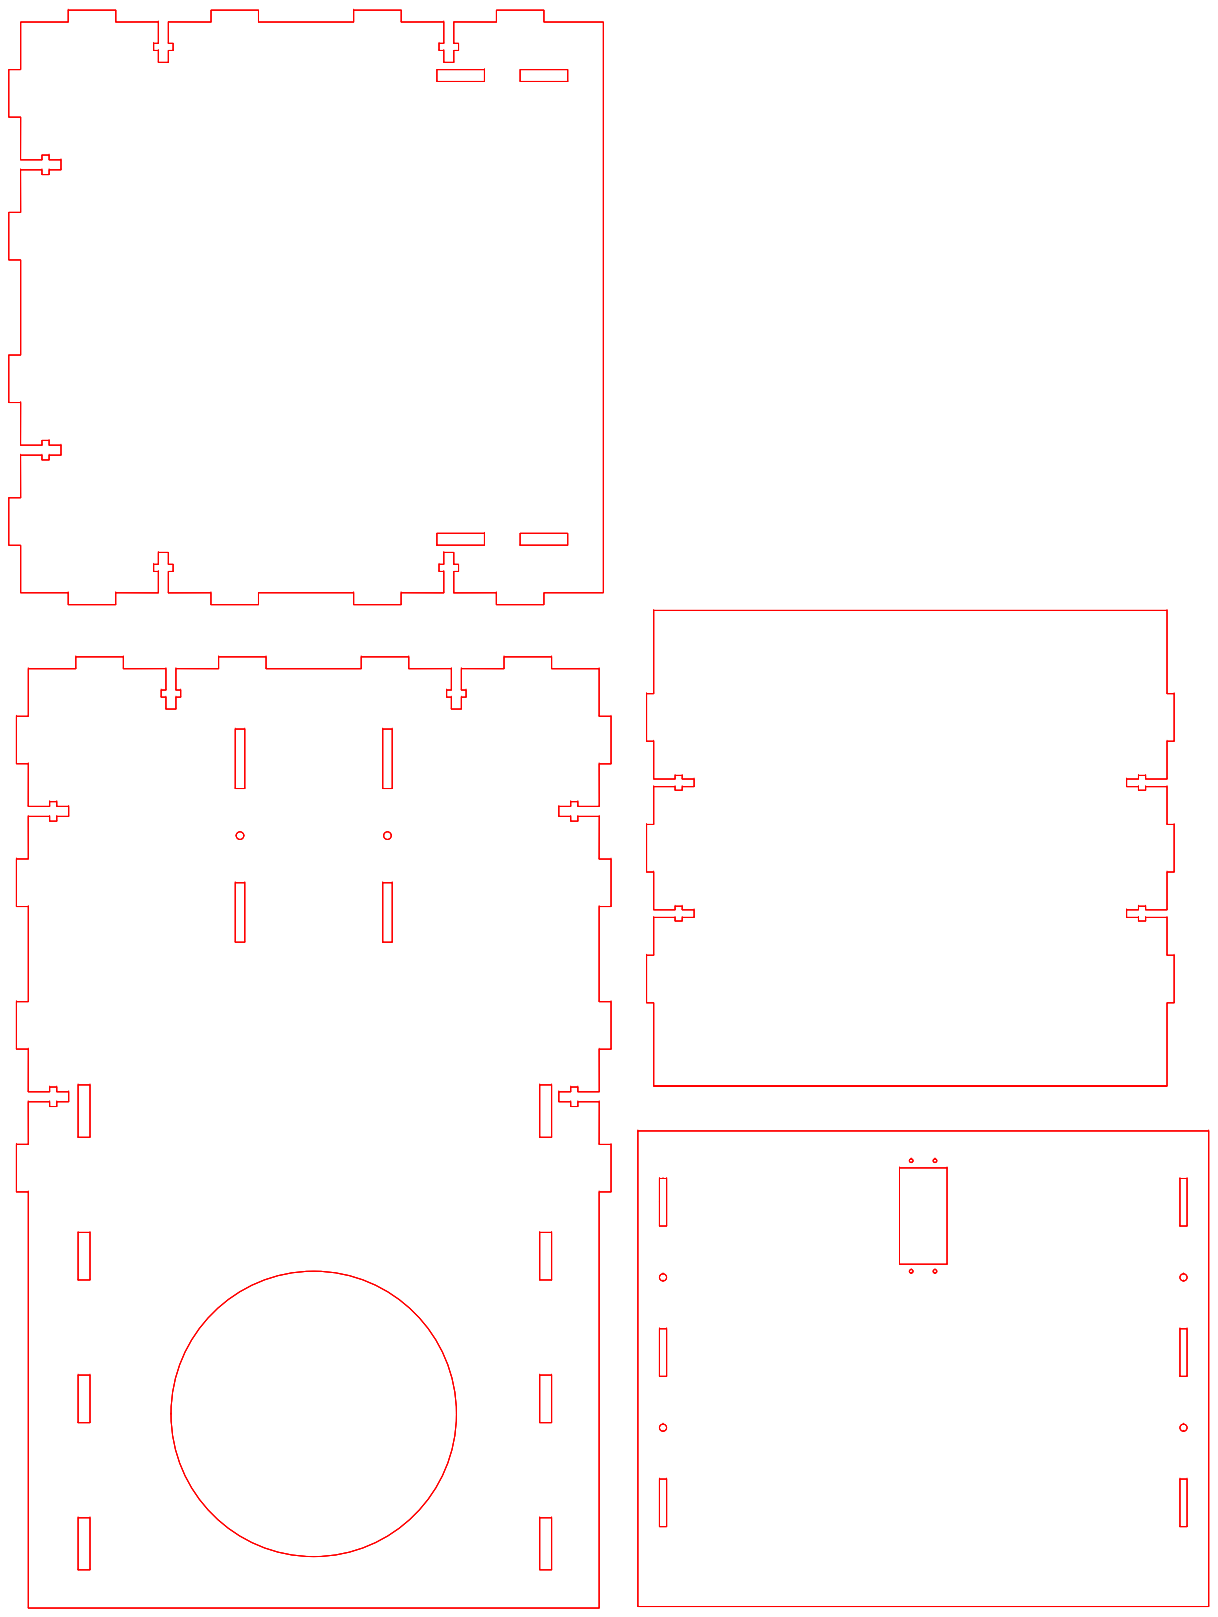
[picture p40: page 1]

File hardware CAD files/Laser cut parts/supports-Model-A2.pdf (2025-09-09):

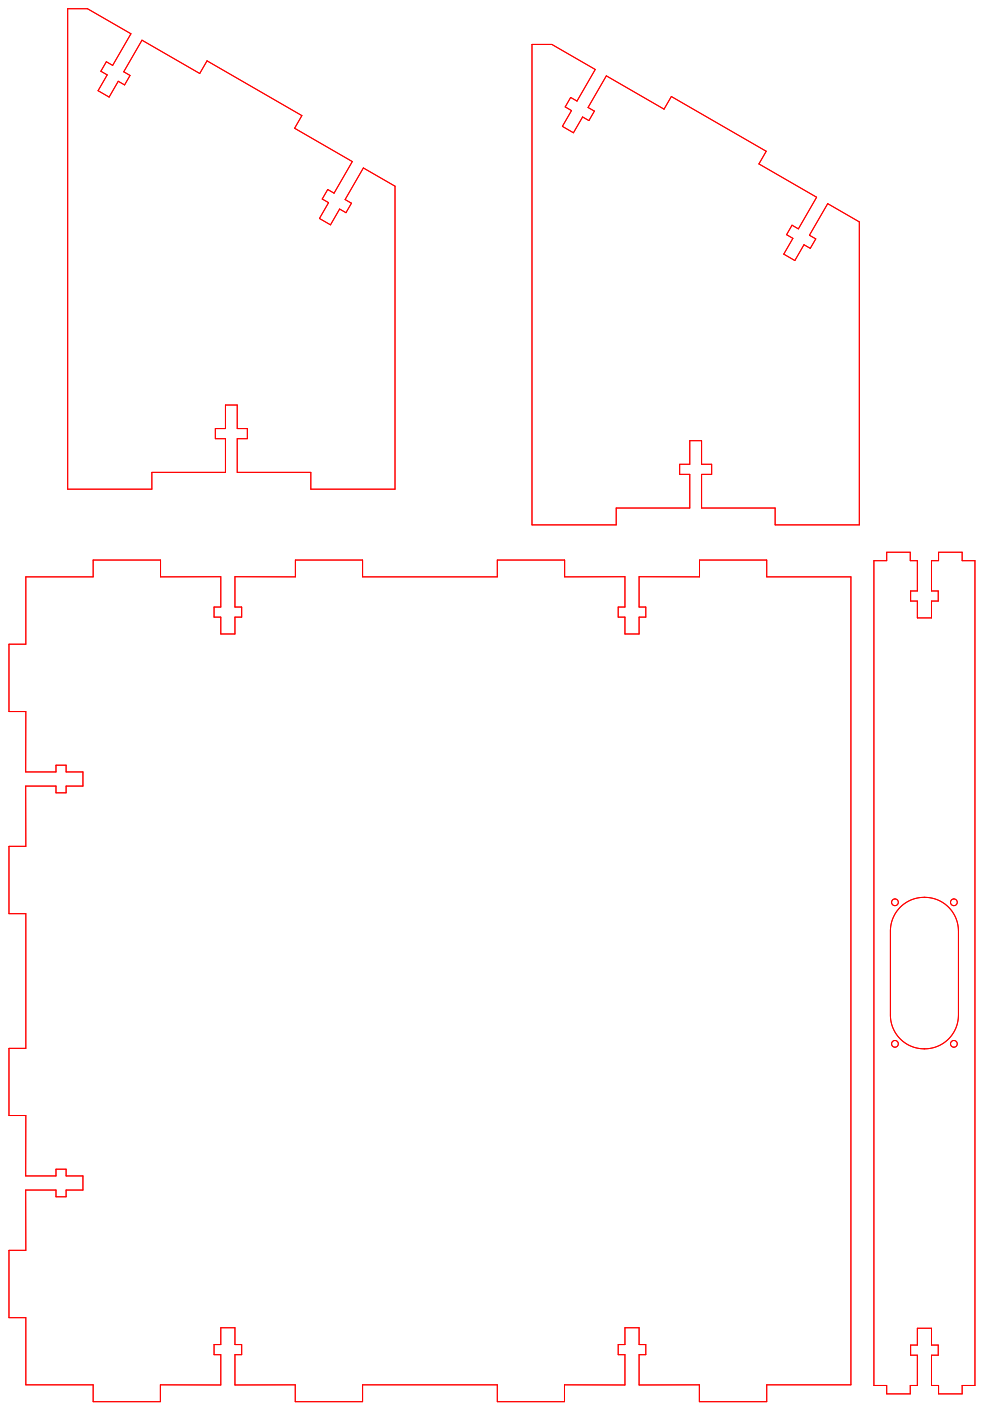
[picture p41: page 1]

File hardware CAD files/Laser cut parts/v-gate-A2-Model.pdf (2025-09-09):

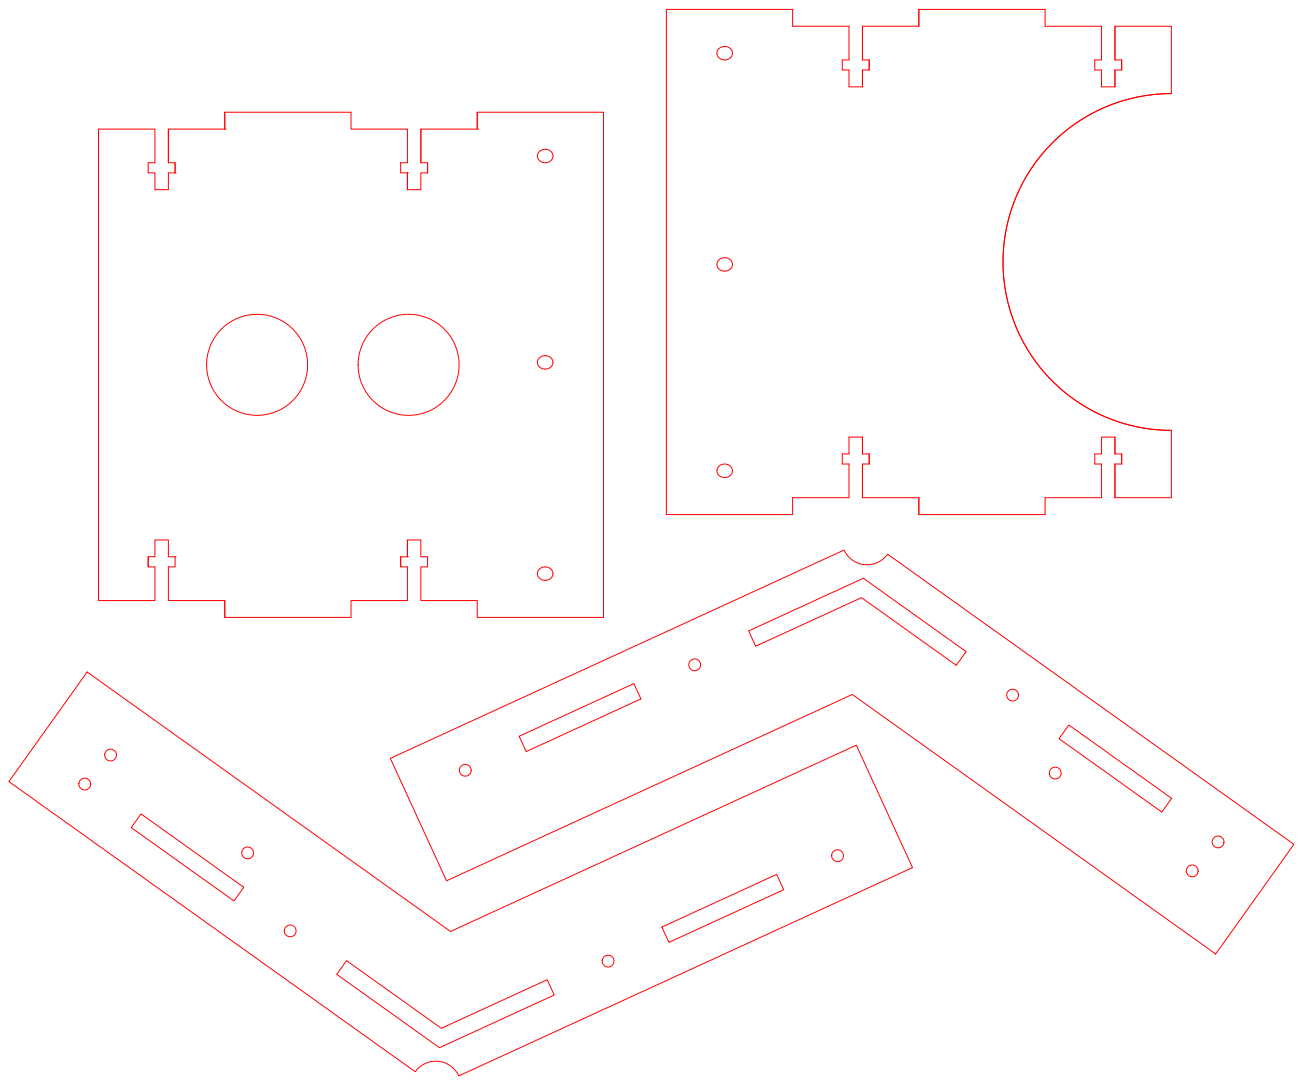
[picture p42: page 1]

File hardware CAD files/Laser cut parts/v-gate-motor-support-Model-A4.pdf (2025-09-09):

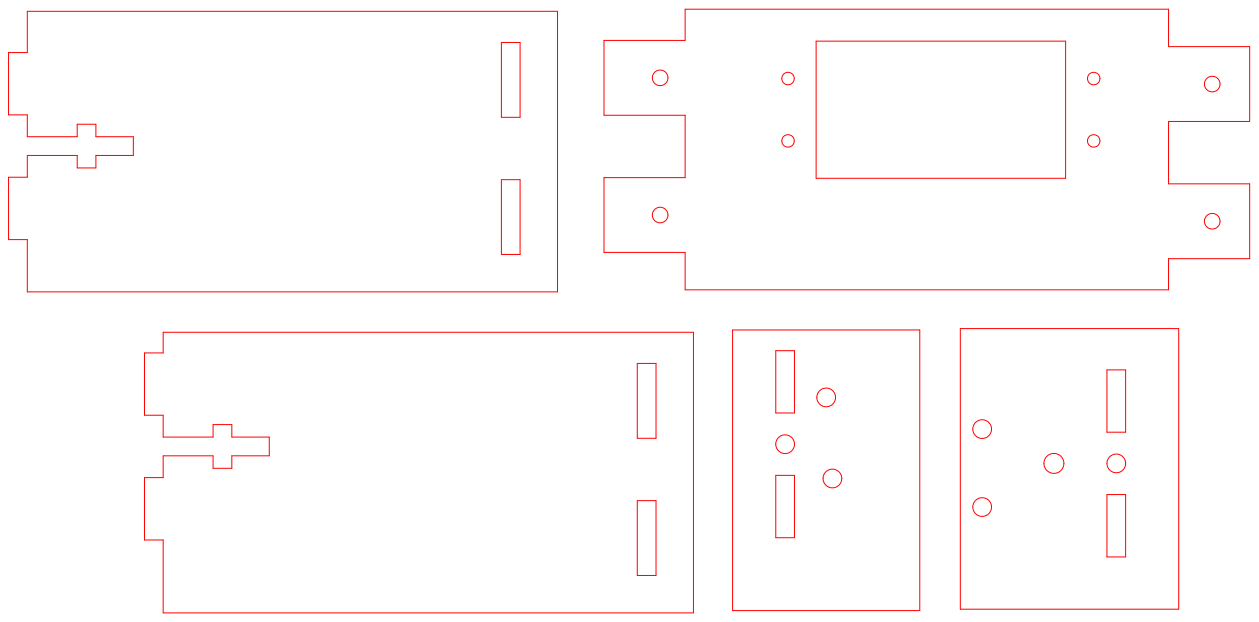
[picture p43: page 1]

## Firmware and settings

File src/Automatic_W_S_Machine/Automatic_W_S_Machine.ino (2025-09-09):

#include <Servo.h>

Servo Pipe_Servo;
Servo Gate_Servo;

// define the variables
int sensorInd = A0; //Pin A0 (analog)
int sensorpin = 2; //Digital Pin nr. 2
int indValue;
const int trigPin = 7;
const int echoPin = 8;
int i=0;
float Pipe_Pos=0.0;
float Gate_Pos=0.0;
int n=0;

long duration;
float distance;

float metalDetected;

void setup() {

pinMode(trigPin, OUTPUT); // trigPin=output
pinMode(echoPin, INPUT); // echoPin = input

Serial.begin(9600); // Starts the serial communication

// Codes that run only once[

//--System Initialization--

    Pipe_Pos=Pipe_Servo.read();//Read the last value given to Pipe servo
    Gate_Pos=Gate_Servo.read();//Read the last value given to Pipe servo

    Serial.println("Motor_PIPE Position");
    Serial.println(Pipe_Pos);
    Serial.println("Motor_GATE Position");
    Serial.println(Gate_Pos);
    delay(5000);

    
    Pipe_Servo.attach(11);


    if (Pipe_Pos<80){
      

      for(i=Pipe_Pos; i<=80; i=i+1){
      Pipe_Servo.write(i);
      delay(15);
      }
    }
      
      else {
        for(i=Pipe_Pos; i>=80; i=i-1){
        Pipe_Servo.write(i);
        delay(15); 
      
        }
      }

delay(1000); //Delay (wait) for servo pipe to go to the bin.

    //Next rotate the gate servo.
    //And control the speed of Gate Servo.
    Gate_Servo.attach(10);

     for(n=0; n<=65;n=n-1){
       Gate_Servo.write(n);
      delay(20); //Controll the speeed of Gate servo 

    }   

    delay(1000); //Delay (wait) and then bring back the Gate_Servo to its
     //initial position.

     //Bring Back Gate_Servo to initial position
     //So from actual position 2-> n=45; we go backwards up to n=0.

     for(n=65; n>=0; n=n-1){ 
      Gate_Servo.write(n);
      delay(25); //Control the speed of Gate servo 
     }

delay(5000);
//--System Initialization--//
// Codes that run only once]
}

void loop() {


//delay(100);
delay(3000);

// Clears the trigPin
digitalWrite(trigPin, LOW);
delayMicroseconds(10);//
// Sets the trigPin on HIGH state for 10 micro seconds
digitalWrite(trigPin, HIGH);
delayMicroseconds(30);//it was 1
digitalWrite(trigPin, LOW);
// Reads the echoPin, returns the sound wave travel time in microseconds
duration = pulseIn(echoPin, HIGH);
// Calculating the distance
distance= duration*0.034/2;
// Prints the distance on the Serial Monitor
Serial.print("Distance: ");
Serial.println(distance);

  

indValue=digitalRead(sensorInd);//Save value that is read from the analog pin A0 to the variable indValue
delay(10);
int sensorstate = digitalRead(sensorpin); // Digital value for Capacitive S.
delay(500);
//metalDetected = (float)indValue*100/1024.0; //from analog value
delay(50);
Pipe_Pos=Pipe_Servo.read();//Read the actual position of Pipe servo
Gate_Pos=Gate_Servo.read();//Read the actual position of Gate servo

Serial.println(indValue);
Serial.println(sensorstate);
//**METAL DETECTED**//


  if(indValue!=1 && sensorstate != 1 && distance<=17){
   Serial.println("Metal Detected");
    Pipe_Pos=Pipe_Servo.read();//Read the last value given to Pipe servo
    Gate_Pos=Gate_Servo.read();//Read the last value given to Pipe servo
    Serial.println("Motor_PIPE Position");
    Serial.println(Pipe_Pos);
    Serial.println("Motor_GATE Position");
    Serial.println(Gate_Pos);


    Serial.println("Motor to metal bin");

    delay(100);
    //Wait for some time after the measurements and move servo to 
    //the corresponding bin

    //For initial position of servo_gate/PIPE in this case the read function will give us the last position of servo
    //in degree
    //Go to the second position of the PIPE servo @90 degree
    //To control the speed of the servo we do this for loop.
    //We have 2 cases 1; when pipe is somewhere in position greater then 90, in this particular case we want to go to 90 so we have to loop back.
    //The other case is to loop forward i=i+1, (meaning to increase the angle in incremental manner).
    
    if (Pipe_Pos<80){

      for(i=Pipe_Pos; i<=80; i=i+1){
      Pipe_Servo.write(i);
      delay(15);
      }
    }
      
      else {
        for(i=Pipe_Pos; i>=80; i=i-1){
        Pipe_Servo.write(i);
        delay(15); 
      
        }
      }

delay(1000); //Delay (wait) for servo pipe to go to the bin.

    //Next rotate the gate servo.
    //And control the speed of Gate Servo.

     for(n=0; n<=65; n=n+1){  
      Gate_Servo.write(n);
      delay(20); 

    }   

    delay(1000); //Delay (wait) and then bring back the Gate_Servo to its initial position.

     //Bring Back Gate_Servo to initial position
     //So from actual position 2--> n=45; we go backwards up to n=0.

     for(n=65; n>=0; n=n-1){  
      Gate_Servo.write(n);
      delay(25);  
     }
    
   //**METAL DETECTED**// 



   //**Wet Waste DETECTED**// 
   
   }

   

//**Plastic DETECTED**// 

else if(indValue==1 && sensorstate == 1 && distance<=17){ 
   Serial.println("Plastic Detected");

    Pipe_Pos=Pipe_Servo.read();//Read the last value given to Pipe servo
    Gate_Pos=Gate_Servo.read();//Read the last value given to Pipe servo
    Serial.println("Motor_PIPE Position");
    Serial.println(Pipe_Pos);
    Serial.println("Motor_GATE Position");
    Serial.println(Gate_Pos);
    Serial.println("Motor to Plastic Bin");

    delay(1000);
    //Wait for some time after the measurements and move servo to 
    //the corresponding bin


    //For initial position of servo_gate/PIPE in this case the read function will give us the last position of servo in degree
    //Go to the second position of the Pipe_Servo @25 degree for Glass
    //To control the speed of the servo we do this for loop.

    //We have 2 cases; when pipe is somewhere in position greater then 90, in this particular case we want to go to 25 so we have to loop back.
    //The other case is to loop forward i=i+1, (meaning to increase the angle in incremental manner).
    //Actually in this case we can have only one case when angle is greater then 25, but however! :P


    if (Pipe_Pos<20){

      for(i=Pipe_Pos; i<=20; i=i+1){
      Pipe_Servo.write(i);
      delay(15);
      }
    }
      
      else {
        for(i=Pipe_Pos; i>=20; i=i-1){
        Pipe_Servo.write(i);
        delay(15); 
      
        }
      }

delay(1000); //Delay (wait) for servo pipe to go to the bin.

    //Next rotate the gate servo.//This remains the same for all other cases
    //And control the speed of Gate Servo.

     for(n=0; n<=65; n=n+1){  
      Gate_Servo.write(n);
      delay(20); 

    }   

    delay(1000); //Delay (wait) and then bring back the Gate_Servo to its
     //initial position.

     //Bring Back Gate_Servo to initial position
     //So from actual position n=45; we go backwards up to n=0.

     for(n=65; n>=0; n=n-1){  
      Gate_Servo.write(n);
      delay(25); 
     }

    Serial.println("Motor_PIPE Position");
    Serial.println(Pipe_Pos);
    Serial.println("Motor_GATE Position");
    Serial.println(Gate_Pos);
}

  else if(indValue==1 && sensorstate != 1 && distance<=17){ 
   delay(100);
   Serial.println("Wet Waste Detected");

    Pipe_Pos=Pipe_Servo.read();//Read the last value given to Pipe servo
    Gate_Pos=Gate_Servo.read();//Read the last value given to Pipe servo
    Serial.println("Motor_PIPE Position");
    Serial.println(Pipe_Pos);
    Serial.println("Motor_GATE Position");
    Serial.println(Gate_Pos);
    Serial.println("Motor to Wet Waste Bin");

    delay(100); //We should tune this but just in case to remmeber
    //Wait for some time after the measurements and move servo to 
    //the corresponding bin

    
    //For initial position of servo_gate/PIPE in this case the read function will give us the last position of servo
    //in degree
    //Go to the second position of the gate Pipe_Servo in degree (145) for Plastic
    //To control the speed of the servo we do this for loop.

    //We have 2 cases 1; when pipe is somewhere in position greater then 145, in this particular case we want to go to 145 so we have to loop back.
    //The other case is to loop forward i=i+1, (meaning to increase the angle in incremental manner)untill we reach the desired angle.
    
    if (Pipe_Pos<50){

      for(i=Pipe_Pos; i<=50; i=i+1){
      Pipe_Servo.write(i);
      delay(15);
      }
    }
      
      else {
        for(i=Pipe_Pos; i>=50; i=i-1){
        Pipe_Servo.write(i);
        delay(15); 
      
        }
      }

delay(1000); //Delay (wait) for servo pipe to go to the bin.

    //Next rotate the gate servo.//This remains the same for all other cases
    //And control the speed of Gate Servo.

     for(n=0; n<=65; n=n+1){  
      Gate_Servo.write(n);
      delay(20); 

    }   

    delay(1000); //Delay (wait) and then bring back the Gate_Servo to its
     //initial position.

     //Bring Back Gate_Servo to initial position
     //So from actual position 2--> n=45; we go backwards up to n=0.

     for(n=65; n>=0; n=n-1){  //Choose the right angle for Gate servo
      Gate_Servo.write(n);
      delay(25); //Controll the speeed of Gate servo (it can be a litle faster now) 
     }
//delay(100);
 
   }

//**Wet Waste DETECTED**// 


}

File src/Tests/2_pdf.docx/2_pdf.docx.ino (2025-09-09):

#include <Servo.h>

// Define the pin number for the sensor and servo motor
const int sensorPin = A0;
const int servoPin = 9;
int n=0;
// Create a Servo object
Servo servoMotor;

void setup() {
  // Attach the servo to the specified pin
  servoMotor.attach(servoPin);

  // Initialize the serial communication for debugging (optional)
  Serial.begin(9600);
}

void loop() {
  // Read the sensor value
  int sensorValue = analogRead(sensorPin);

  // Map the sensor value to the servo angle (0 to 45)
  if (digitalRead(sensorPin)==HIGH){
    if (servoMotor.read()==45)
    {
      servoMotor.write(45);
    }
    else
    {
       for(n=servoMotor.read();n<=45;n=n+1)
       {
          servoMotor.write(n);
          delay(10);
       }
    }
  }
 delay(1000);
 
 if (servoMotor.read()==0)
    {
      servoMotor.write(0);
    }
 else
    {
      for(n=servoMotor.read();n>=0;n=n-1)
      {
         servoMotor.write(n);
         delay(10);
      }
    }



  // Wait for a short delay before the next iteration

}
